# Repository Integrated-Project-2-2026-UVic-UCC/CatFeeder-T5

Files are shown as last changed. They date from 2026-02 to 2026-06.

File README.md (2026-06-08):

# 🐱 Automatic Cat Feeder

Modular automatic cat feeder based on an ESP32 microcontroller, a NEMA 17 stepper motor, closed-loop weight feedback, scheduled feeding, and local user interaction through a TFT touch display.

The goal of this project is to design and build a low-cost mechatronic prototype capable of dispensing controlled portions of dry cat food at scheduled times. The system combines mechanical design, 3D printing, electronics, embedded firmware, sensor calibration, and power management.

---

<p align="center">
  Automatic Cat Feeder Prototype
</p>

## 📌 Project Overview

Automatic cat feeders are useful embedded systems because they combine several engineering areas in a single functional product:

* Mechanical food storage and dispensing.
* Stepper motor actuation.
* Weight-based portion control.
* Real-time scheduling.
* Sensor integration.
* Local user interface.
* Power supply and backup operation.

This prototype uses an auger screw mechanism driven by a NEMA 17 stepper motor. The amount of food dispensed is measured using a load cell and an HX711 amplifier, allowing the system to stop the motor when the target portion has been reached.

---

## 🎥 Commercial Video

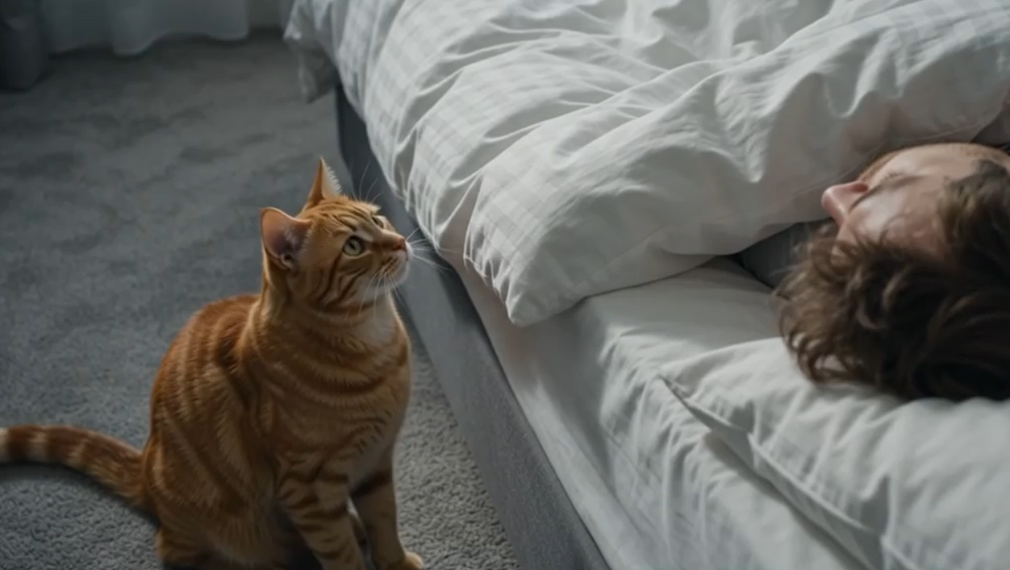
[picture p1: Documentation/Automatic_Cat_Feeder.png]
Watch the commercial video (https://universitatdevic.sharepoint.com/:v:/t/IntegratedProjectII-GR15GEMEC-09UV-Equip/IQAjYwX-qLkBQKHNnmvlTQq8AcUehd5CAwjfhSMxtLNW64w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)


Click the image above to watch the commercial video of the Automatic Cat Feeder prototype.

---

## 🎯 Main Features

* Scheduled automatic feeding.
* Manual food dispensing.
* Closed-loop portion control using a load cell.
* NEMA 17 stepper motor actuation.
* DRV8825 stepper motor driver.
* ESP32 WROOM-32 control unit.
* DS3231 real-time clock for offline timekeeping.
* DHT22 temperature and humidity monitoring.
* 3.5-inch TFT touch display for local interaction.
* 12 V UPS / battery system for backup power.
* Modular mechanical design with 3D-printed parts.
* Low-cost prototype architecture.

---

## 🧩 System Architecture

The prototype is divided into four main subsystems:

| Subsystem | Description |
| --- | --- |
| Mechanical system | Food hopper, main body, auger screw, motor mount, bowl support, and electronics enclosure |
| Electrical system | ESP32, DRV8825, NEMA 17 motor, HX711, load cell, RTC, DHT22, TFT display, and UPS |
| Firmware | Feeding logic, motor control, sensor reading, scheduling, calibration, and user interface |
| Validation | Portion accuracy tests, repeatability tests, scheduled feeding tests, and power consumption tests |

The food is stored in the upper hopper and moves by gravity toward the lower dispensing area. The auger screw moves the food toward the outlet, while the load cell measures the real amount of food dispensed into the bowl.

---

## 🛠️ Mechanical Design

The mechanical structure is designed to be manufactured mainly using FDM 3D printing. The prototype prioritizes low cost, modularity, ease of assembly, and adaptability to different dry food sizes.

### 3D-Printed Parts

| Part | Description | Recommended Material | Notes |
| --- | --- | --- | --- |
| Main body | Main structural frame of the feeder | PLA / PETG | Supports the hopper, motor, electronics, and bowl area |
| Food hopper | Stores dry cat food | PETG recommended | Smooth internal walls recommended |
| Auger screw / dispensing screw | Moves food from the hopper to the outlet | PETG recommended | Must be tested with the real kibble size |
| Bowl support | Holds the bowl and load cell system | PLA / PETG | Should avoid unwanted movement during weighing |
| Motor mount | Holds the NEMA 17 motor in position | PETG / ABS | Must keep the motor aligned with the dispensing screw  |
| Electronics cover | Protects the electronics and wiring | PLA / PETG | Ventilation openings recommended |

---

## 🧾 Mechanical and Hardware Parts

The mechanical structure of the feeder is based mainly on 3D-printed parts and standard assembly hardware. The final dimensions and quantities may vary depending on the selected enclosure, hopper size, and screw mechanism.

| Image | Part | Description | Quantity | Notes |
| --- | --- | --- | ---: | --- |
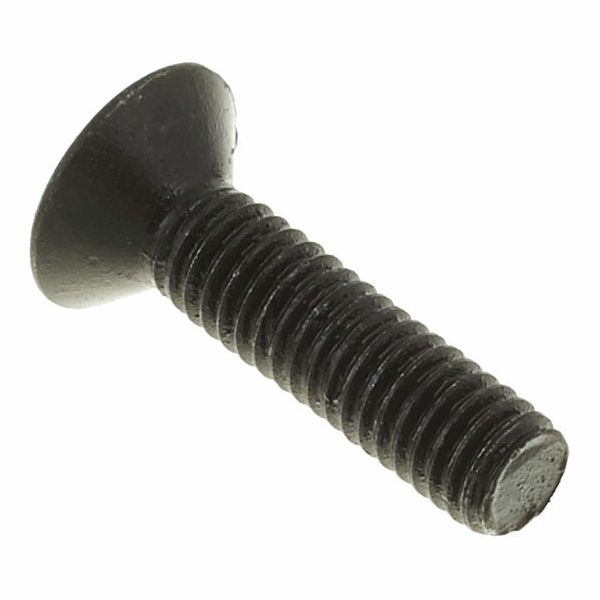
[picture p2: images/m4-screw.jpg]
|  | M4 screws | General assembly screws | 10–20 pcs | Final length depends on the 3D-printed parts  |
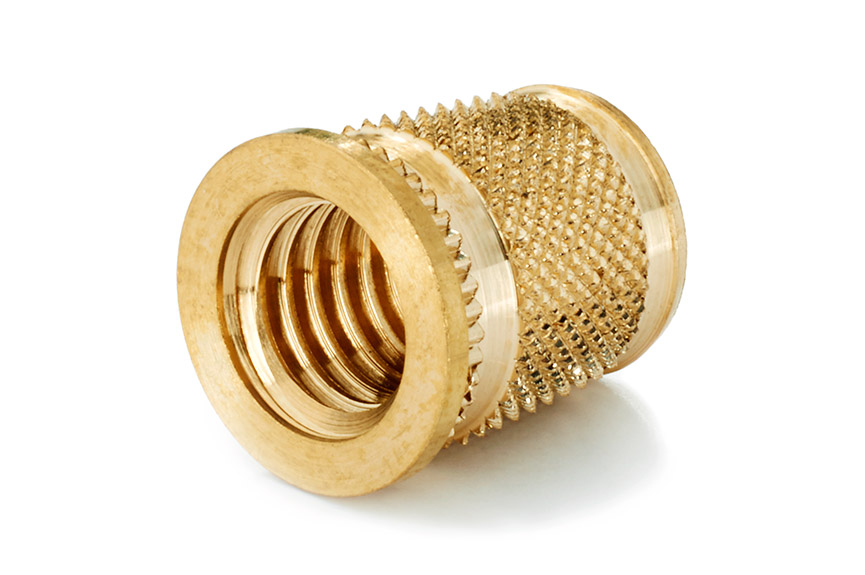
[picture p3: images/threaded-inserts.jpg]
|  | Threaded inserts | Metal inserts for stronger screw mounting | Optional | Recommended for repeated disassembly |
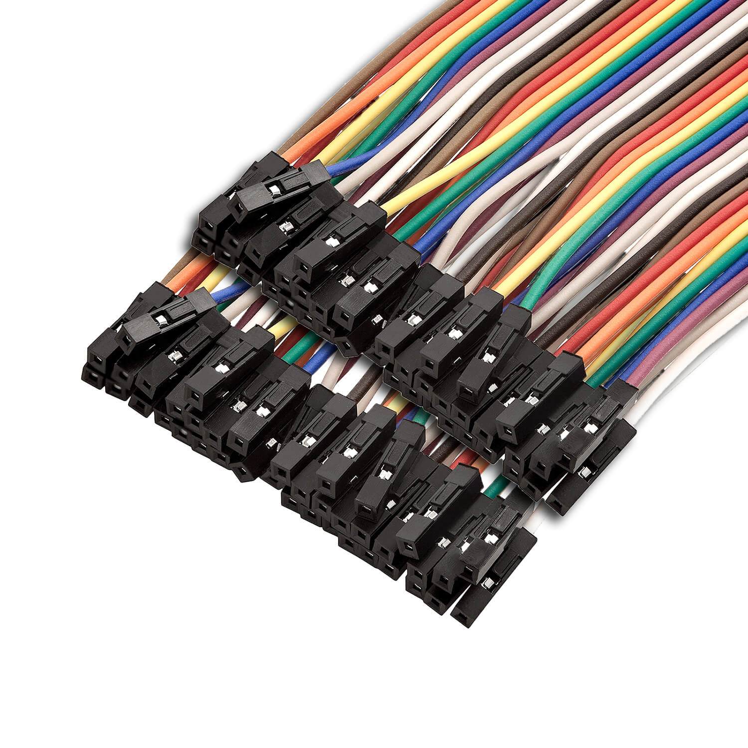
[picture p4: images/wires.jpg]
|  | Wires / jumper cables | Electrical connections | As required | Use suitable wire gauge for motor power lines |
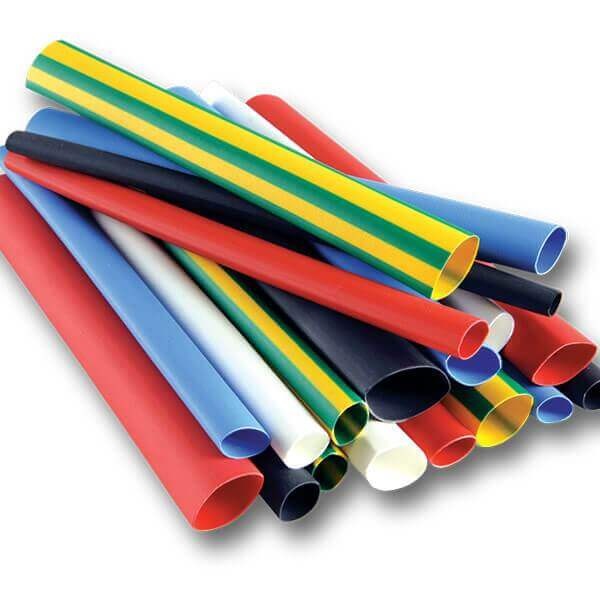
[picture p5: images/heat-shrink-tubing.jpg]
|  | Heat-shrink tubing | Wire insulation and protection | As required | Recommended for safer wiring |

---

## ⚡ Electronic Components

The electrical architecture is built around the ESP32 WROOM-32 microcontroller. The ESP32 controls the actuator, reads the sensors, manages the feeding schedule, and communicates with the local user interface.

| Image | Component | Quantity | Description | Purpose |
| --- | --- | ---: | --- | --- |
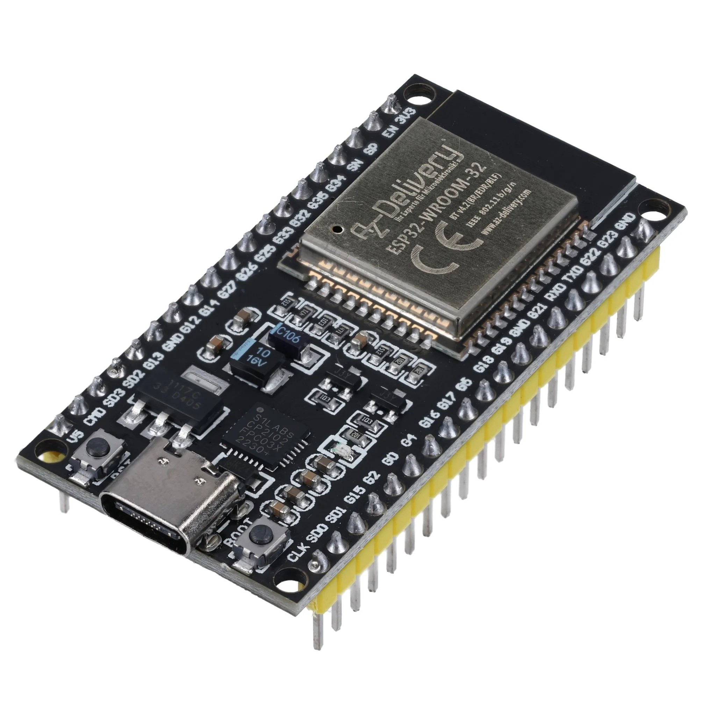
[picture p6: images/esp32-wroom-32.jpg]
|  | ESP32 WROOM-32 | 1 | Wi-Fi and Bluetooth capable microcontroller | Main control unit |
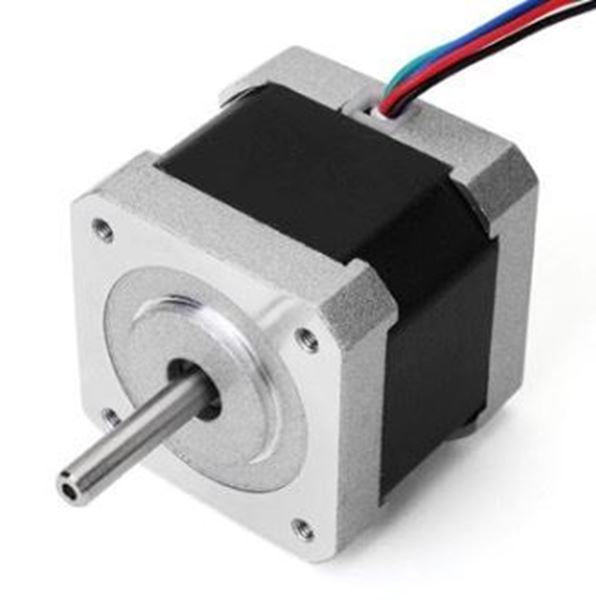
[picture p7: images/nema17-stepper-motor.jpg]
|  | NEMA 17 stepper motor | 1 | Bipolar stepper motor | Rotates the dispensing mechanism |
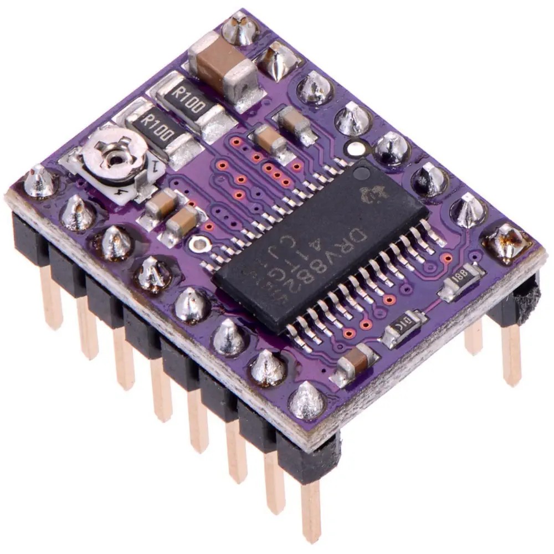
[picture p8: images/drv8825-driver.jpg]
|  | DRV8825 stepper motor driver | 1 | Stepper motor driver module | Drives the NEMA 17 motor from ESP32 control signals |
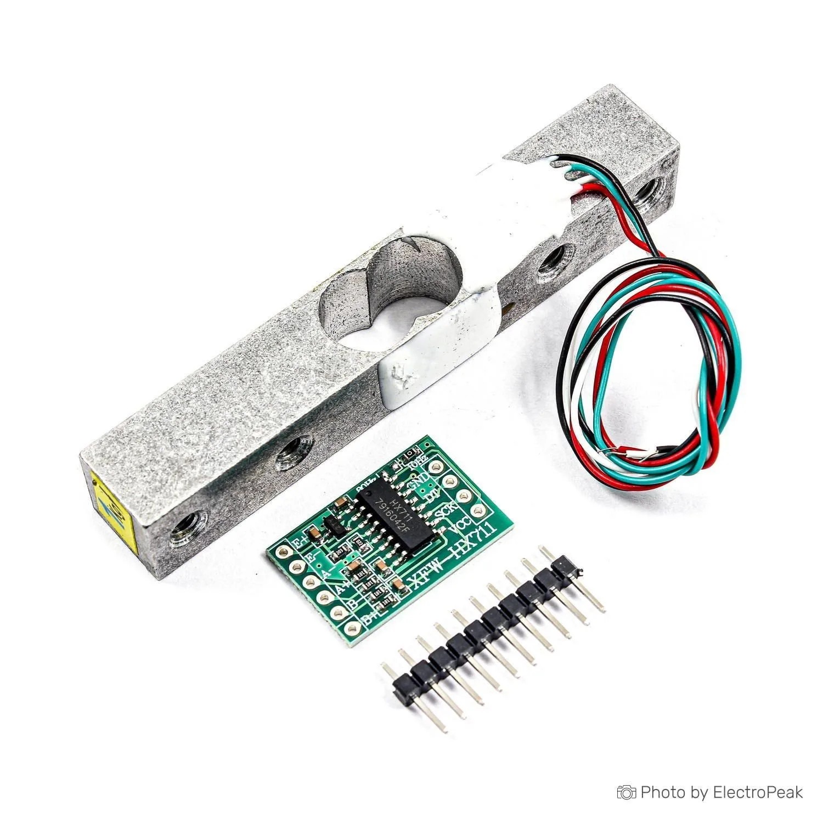
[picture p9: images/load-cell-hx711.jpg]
|  | Load cell 1 kg + HX711 | 1 | Weight sensor and 24-bit ADC amplifier | Measures the dispensed food portion |
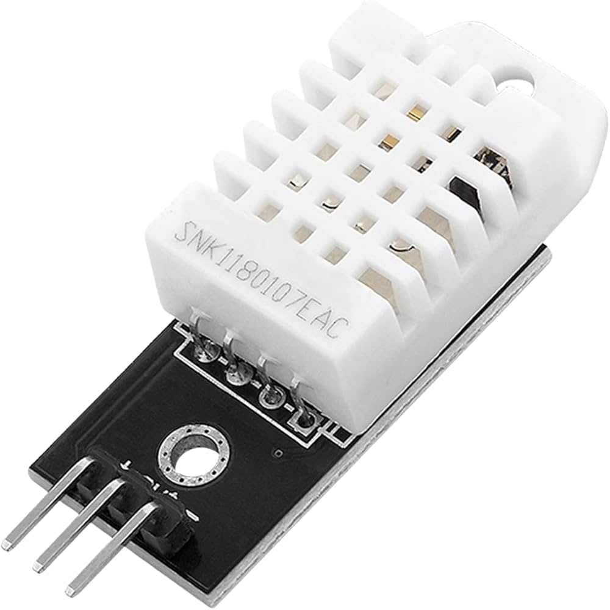
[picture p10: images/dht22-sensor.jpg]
|  | DHT22 | 1 | Temperature and humidity sensor | Monitors food storage conditions |
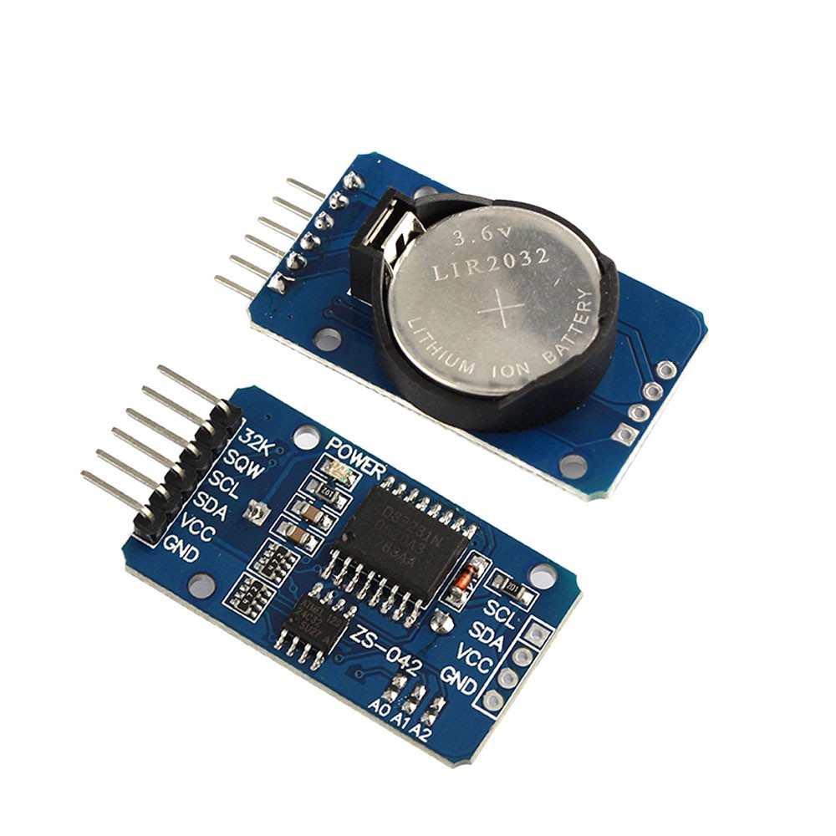
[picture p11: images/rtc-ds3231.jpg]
|  | RTC DS3231 | 1 | Real-time clock module | Keeps accurate feeding schedules without Wi-Fi |
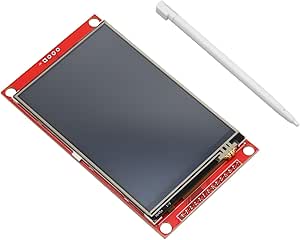
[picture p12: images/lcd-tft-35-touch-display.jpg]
|  | 3.5-inch TFT touch display | 1 | Local touchscreen interface | Displays information and allows local configuration |
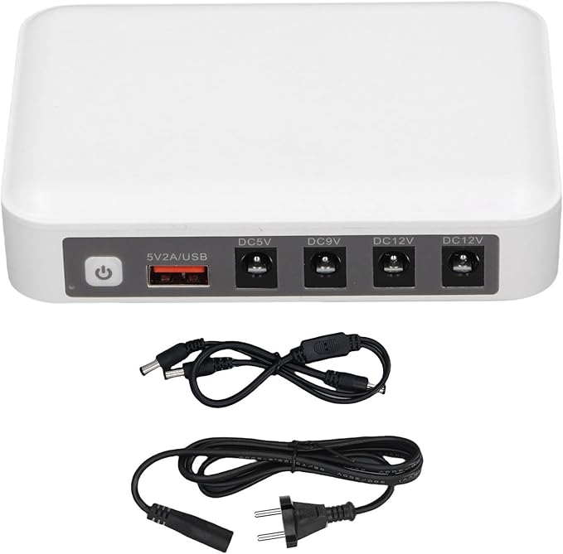
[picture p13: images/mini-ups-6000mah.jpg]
|  | 12 V Mini UPS / battery system | 1 | Backup power supply | Keeps the feeder powered during short outages |
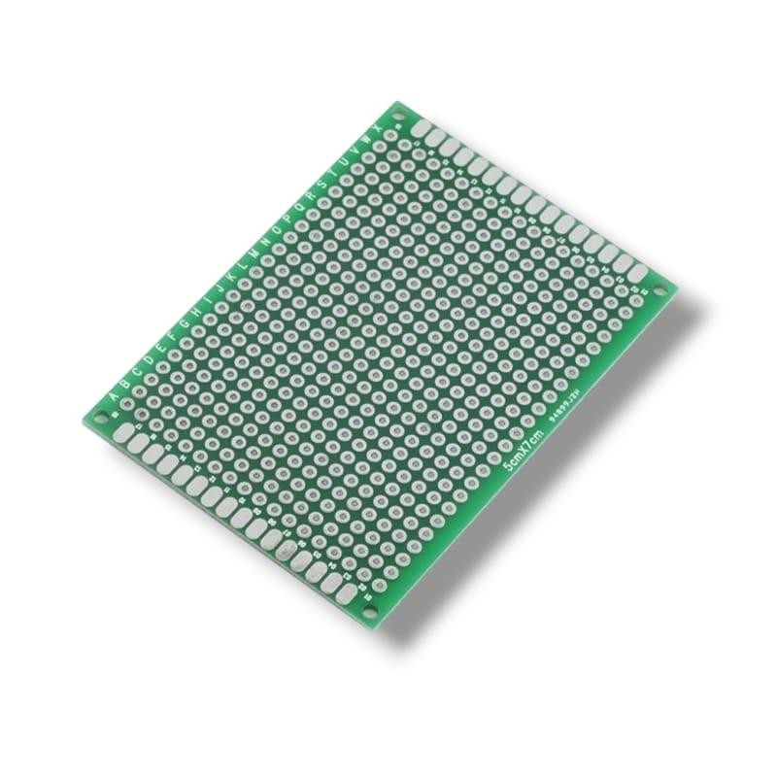
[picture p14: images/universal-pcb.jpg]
|  | Universal double-sided PCB | 1 | Prototyping PCB | Used for mounting and organizing the circuit |

---

## 🔌 Power Architecture

The system uses three voltage levels:

| Voltage Rail | Usage |
| --- | --- |
| 12 V | NEMA 17 stepper motor through the DRV8825 driver |
| 5 V | ESP32 development board and selected modules |
| 3.3 V | ESP32 logic level and compatible low-power modules |

All voltage rails must share a common ground reference. This is required to ensure that control signals and sensor communication lines are interpreted correctly.

> ⚠️ The DRV8825 current limit must be adjusted according to the rated current of the selected NEMA 17 motor. A bulk capacitor should also be placed close to the motor power input of the driver to reduce voltage spikes generated by the inductive load.

---

## 🧠 ESP32 GPIO Mapping

| Target Component | Peripheral Pin | ESP32 GPIO | Description |
| --- | --- | ---: | --- |
| DRV8825 | STEP | GPIO 26 | Step pulse output |
| DRV8825 | DIR | GPIO 27 | Direction control |
| DRV8825 | ENABLE | GPIO 14 | Driver enable / power saving  |
| HX711 | DOUT | GPIO 32 | Load cell data |
| HX711 | PD_SCK | GPIO 33 | Load cell clock |
| DS3231 RTC | SDA | GPIO 21 | I2C data |
| DS3231 RTC | SCL | GPIO 22 | I2C clock |
| DHT22 | DATA | GPIO 4 | Temperature and humidity data |
| TFT Display | SPI_CLK | GPIO 18 | SPI clock |
| TFT Display | SPI_MISO | GPIO 19 | SPI MISO |
| TFT Display | SPI_MOSI | GPIO 23 | SPI MOSI |
| TFT Display | TFT_CS | GPIO 15 | Display chip select |
| TFT Display | TFT_DC | GPIO 2 | Data / command selection |

> ⚠️ Some ESP32 pins are strapping pins and can affect boot behaviour. GPIO 0, GPIO 2, GPIO 5, GPIO 12, and GPIO 15 must be used carefully.

---

## 💻 Firmware

The firmware is developed in C/C++ using the Arduino framework for ESP32.

The software controls:

* Scheduled feeding.
* Manual dispensing.
* Motor movement.
* Load cell readings.
* RTC timekeeping.
* DHT22 environmental readings.
* TFT display interface.
* Basic safety checks.
* Power-saving behaviour.

---

## 🔁 Control Algorithm

The feeding cycle follows this sequence:

1. Read the current time from the DS3231 RTC.
2. Compare the current time with the programmed feeding schedule.
3. If a feeding event is required, enable the DRV8825 driver.
4. Start rotating the NEMA 17 motor.
5. Move food through the auger screw.
6. Read the load cell using the HX711 amplifier.
7. Compare the measured weight with the target portion.
8. Stop the motor when the desired portion is reached.
9. Disable the motor driver to reduce power consumption.
10. Store or display the feeding result.

---

## ⚖️ Calibration

Calibration is required before using the feeder.

### Load Cell Calibration

The load cell must be calibrated using known reference weights.

Recommended process:

1. Place the empty bowl on the load cell.
2. Tare the system.
3. Place a known weight on the bowl.
4. Read the raw HX711 value.
5. Calculate the scale factor.
6. Repeat the process with different weights.
7. Store the final calibration factor in the firmware configuration.

### Portion Calibration

Different dry foods have different shapes and densities. For this reason, the dispensing system must be tested with the real kibble.

Recommended process:

1. Set a target portion, for example 20 g.
2. Run the dispensing cycle.
3. Measure the real dispensed mass.
4. Repeat several times.
5. Calculate the average error.
6. Adjust motor speed, acceleration, or stopping threshold if required.

---

## 🧪 Validation Tests

| Test | Objective | Expected Result |
| --- | --- | --- |
| Dispensing mechanism test | Verify food movement through the auger screw | Food is dispensed without blockage |
| Portion accuracy test | Compare target mass with real mass | Low dispensing error |
| Repeatability test | Repeat the same portion several times | Similar mass between cycles |
| Scheduled feeding test | Verify RTC-based activation | Feeder activates at programmed times |
| Power consumption test | Measure 12 V and 5 V consumption | Consumption within estimated range |

---

## 📊 Technical Targets

| Parameter | Target / Estimated Value |
| --- | ---: |
| Food capacity | Approximately 3 kg |
| Estimated autonomy |  Approximately 45.6 days |
| Daily food quantity | Approximately 65.8 g/day |
| Required motor torque | 0.199 N·m |
| Selected motor torque | 0.4 N·m |
| Safety factor | 2.01 |
| Estimated daily energy consumption | 0.73–2 Wh/day |

---

## 🧮 Prototype Material Cost

| Item | Component | Quantity | Unit Price [€] | Cost [€] | Provider  |
| ---: | --- | ---: | ---: | ---: | --- |
| 1 | NEMA 17 stepper motor | 1 | 14.00 | 14.00 | Amazon |
| 2 | ESP32 WROOM-32 | 1 | 13.00 | 13.00 | Amazon |
| 3 | Load Cell 1 kg + HX711 | 1 | 20.00 | 20.00 | Amazon |
| 4 | DHT22 temperature and humidity sensor | 1 | 9.99 | 9.99 | Robotshop |
| 5 | PLA 1 kg | 1 | 13.00 | 13.00 | Amazon |
| 6 | Universal double-sided PCB, 9 x 15 cm, 10 units | 1 | 10.17 | 10.17 | Amazon |
| 7 | DRV8825 stepper motor driver | 1 | 19.24 | 19.24 | Robotshop |
| 8 | RTC DS3231 | 1 | 4.50 | 4.50 | Amazon |
| 9 | SAI Mini UPS 6000 mAh | 1 | 39.90 | 39.90 | Amazon |
| 10 | 3.5-inch LCD TFT touch display | 1 | 16.14 | 16.14 | Amazon |
| | **Total material cost** | | | **159.94** | |

---

## 🧯 Safety Notes

* Do not power the NEMA 17 motor directly from the ESP32.
* Always use a dedicated stepper motor driver.
* Adjust the DRV8825 current limit before connecting the motor.
* Use a common ground between the ESP32, driver, sensors, and power supply.
* Avoid loose wires near the moving dispensing mechanism.
* Protect the electronics from food dust and humidity.
* Test the system without food before performing real dispensing tests.
* Do not leave the feeder unattended until the prototype has been validated.
* Disconnect the power supply before modifying wiring.
* Check motor and driver temperature during long tests.

---

## 🚀 Future Improvements

* Mobile application integration.
* Remote configuration through a cloud backend.
* Food level detection.
* Improved enclosure design.
* Better humidity protection.
* Long-term reliability testing.
* Advanced calibration procedure.
* Notification system for low food level or failed dispensing.
* AI-assisted feeding analysis based on historical data.
* Improved user interface for feeding schedules and calibration.
* Additional safety detection for mechanical jams.

---

## 👥 Authors

* Ferran Vila Ordeig
* Biel Tomàs Rifà
* Pol Roch Jose
* Georgina Garcia Vilaseca

Degree in Mechatronics Engineering
Subject: Integrated Projects II
University of Vic - Central University of Catalonia

---

## 📄 License

This project is intended for academic and educational purposes.

Add a license file if the project is going to be published publicly.

Recommended licenses:

* MIT License for open-source software.
* CERN Open Hardware Licence for hardware designs.
* Creative Commons license for documentation and 3D models.

---

## 📚 Documentation

The complete technical document includes:

* State of the art and benchmarking.
* Objectives.
* Mechanical design.
* Electrical design.
* Design calculations.
* Control strategy.
* Functional testing plan.
* Cost estimation.
* Conclusions.
* Electrical schematic appendix.

The final report should be stored in the `docs/` folder when available.

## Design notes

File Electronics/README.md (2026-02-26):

# ⚡ Electronics System  
**Automatic Cat Feeder – Integrated Project II (GR15 [GEMEC-09UV])**  
Universitat de Vic – Universitat Central de Catalunya  
Academic Year 2025–2026  

---

## 📌 Overview

This folder contains the complete design and documentation of the **electronic subsystem** of the automatic cat feeder.

The electronics system is responsible for:

- Precise motor control  
- Accurate weight measurement  
- Reliable time-based operation  
- Safe power distribution  
- Hardware-level protection mechanisms  

The design prioritizes **robustness, electrical safety, noise immunity, and modular expandability**, ensuring reliable long-term operation under real-world conditions.

---

## 🎯 Electronics Objectives

- Provide stable and regulated power to all subsystems  
- Control the dispensing motor safely and efficiently  
- Measure dispensed food weight using a load cell system  
- Interface reliably with the microcontroller (ESP32 / Arduino-based platform)  
- Prevent electrical faults (overcurrent, reverse polarity, voltage spikes)  
- Minimize electromagnetic interference (EMI)  
- Ensure maintainability and future scalability  

---

## 🧩 System Architecture

The electronics subsystem is composed of the following modules:

### 1️⃣ Control Unit
- Microcontroller (ESP32 / Arduino platform)  
- GPIO control for motor driver  
- HX711 communication (load cell ADC)  
- Scheduling interface with firmware  

### 2️⃣ Motor Control Stage
- DC motor driver 
- Flyback protection  
- Current limitation strategy  
- Thermal considerations  

### 3️⃣ Weight Measurement System
- Load cell (strain gauge bridge)  
- HX711 24-bit ADC  
- Hardware noise filtering  
- Stable reference and grounding strategy  

### 4️⃣ Power Management
- Input supply stage  
- Voltage regulation (buck / linear regulators)  
- Reverse polarity protection  
- Decoupling and filtering  
- Star-ground topology  

---

## 📂 Folder Structure
electronics/

- schematics/          → Circuit schematics (PDF / CAD files)
- pcb/                 → PCB layout files (if applicable)
- datasheets/          → Relevant component datasheets
- calculations/        → Design calculations (power, current, filtering)
- testing/             → Validation and measurement reports
- README.md            → This document

---

## ⚙️ Key Components

| Component | Function |
|---|---|
| ESP32 / Arduino  | Main control unit |
| HX711 | 24-bit ADC for load cell |
| Load Cell | Food weight measurement |
| Motor Driver | DC motor control |
| Voltage Regulator| Stable power supply |

---

## 📚 References

- ESP32 Technical Reference Manual  
- HX711 Datasheet  
- Load Cell Application Notes  
- TI / ST Microelectronics Power Design Guidelines  
- IPC-2221 PCB Design Standard  

(Complete references available in Milestone documentation)

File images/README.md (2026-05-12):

# Images

This folder contains the images used in the main `README.md` file of the **Automatic Cat Feeder** project.

The images are mainly used to document the electronic components, mechanical parts, wiring, assembly process, and final prototype.

---

## Folder purpose

The purpose of this folder is to keep all project images organized in one place, instead of linking external images directly inside the README.

This makes the documentation easier to maintain and more reliable when the project is uploaded to GitHub.

---

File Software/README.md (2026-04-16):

# CatFeeder - Software Components

This directory contains the entire software stack for the smart CatFeeder project, consisting of a production-grade web application, an IoT firmware simulation, and supporting design resources.

## Architecture Overview

The software is divided into the following main functional components:

1.  **Web Application (`webapp/`)**: A React-based interface allowing users to monitor their cat's data, manage feeding schedules, and interact with the physical device.
2.  **Firmware Mock (`firmware/`)**: An Arduino C++ firmware for the ESP32 that completely mocks the physical sensors and actuators (to be replaced with actual physical components).
3.  **Agent Resources (`agent/`)**: Skills and guidelines focusing on strong frontend design aesthetic and prompt specifications.
4.  **Specifications & Design Assets**:
    *   `SRS_CatFeeder_WebApp.docx.md`: The Software Requirements Specification outlining system capabilities.
    *   `diseño_ui.png`: High-fidelity UI design reference.

---

## 1. Web Application (`webapp/`)

A responsive, bespoke frontend application designed with a strong emphasis on intentional aesthetics and smooth performance. It serves as the primary control panel for the project.

### Tech Stack & Libraries
*   **React 19 & Vite**: The core foundation, providing blazing-fast initialization and HMR.
*   **React Router v7**: For robust client-side routing across sections (*Dashboard, Cats, Schedules, History, Device, Settings, Chat*).
*   **Supabase Client**: Provides BaaS capabilities for PostgreSQL database interactions, real-time subscriptions, and authentication (`@supabase/supabase-js`).
*   **Zustand**: A small, fast, and scalable bearbones state-management solution for handling authentication sessions and global UI state.
*   **Recharts**: Used for rendering visual data analytics, such as the history of cat feeding patterns and weight variations.
*   **Vanilla CSS**: Custom styling following strict frontend design mandates. Prevents over-reliance on utility frameworks, achieving a distinct and premium interface.

### Application Workflow
1.  **Auth & Session**: Handled globally in `App.jsx` using `useAuthStore` (Zustand). Only authenticated users are routed past the `<PrivateRoute>` wrapper into the layout.
2.  **Database Integration**: Pages execute queries using the Supabase client to fetch table information (`cats`, `schedules`, `commands`, `devices`, `feed_events`).
3.  **Hardware Control**: To dispense food or tare the scale, the webapp pushes a new row into the `commands` table. The ESP32 device actively listens to this table.
4.  **Real-time Monitoring**: The dashboard visualizes telemetry (temperature, humidity, scale weight) inserted into Supabase by the physical device.

### Running Locally
You will need Node.js installed. In your terminal:
```bash
cd webapp
npm install 
npm run dev
```
*(Ensure `.env` contains your `VITE_SUPABASE_URL` and `VITE_SUPABASE_ANON_KEY` variables to successfully interact with the database).*

---

## 2. Firmware Simulation (`firmware/`)

Located at `firmware/CatFeeder_Mock/CatFeeder_Mock.ino`, this Arduino C++ instance ensures full end-to-end functionality of the platform without needing the final hardware assembly.

### Core Features
*   **Target Board**: Designed for ESP32 (WROOM-32).
*   **Direct Cloud Integration**: Connects straight to the Supabase REST API via `HTTPClient` and `WiFiClientSecure` using an API JWT authorization header.
*   **Bi-directional Communication**:
    *   **Polling (GET)**: Fetches `device_config` (every 60s) and checks the `commands` table for pending actions (every 5s).
    *   **Pushing (POST/PATCH)**: Sends `realtime_weight` during active operations (`500ms`) and updates device `heartbeat` statuses.
*   **Virtual Sensors & Actuators**: Calculates pseudo-random Gaussian noise behavior across variables:
    *   **Scale**: Mimics the HX711 Load Cell behaviors.
    *   **Environment**: Simulates a DHT22 module to relay Temperature & Humidity.
    *   **Dispenser Motor**: Simulates DRV8825 logic with timeout safety guards, "dispensing" at a fake `8.0g/s` feed rate.

### Usage Setup
1.  Open `CatFeeder_Mock.ino` with the Arduino IDE. 
2.  Install the **ArduinoJson** (`v7.x`) library from the Library Manager.
3.  Update the network credentials (`WIFI_SSID`, `WIFI_PASS`) and endpoint configs (`SUPABASE_URL`, `SUPABASE_KEY`, `DEVICE_ID`).
4.  Upload to your ESP32 board and open the Serial Monitor at `115200` baud.

---

## 3. Architectural Note

This software adopts an asynchronous, database-as-the-broker architecture. The web application and the ESP32 never communicate with each other directly; they only write to or listen to the Supabase database. This guarantees a decoupled, resilient system. Row Level Security (RLS) rules in Supabase must be set up properly to make sure IoT requests only interact with permitted device rows.

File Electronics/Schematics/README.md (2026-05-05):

# Schematics

This folder contains the electrical schematics of the Automatic Cat Feeder project.

The schematics define how the electronic components are connected, including the microcontroller, sensors, actuators, power supply, protection elements, and communication signals.

## Purpose

The purpose of this folder is to:

- Document the electrical design of the project.
- Show how each electronic component is connected.
- Support wiring, debugging, and testing.
- Keep editable schematic files and exported versions organized.
- Track changes between schematic revisions.
- Help detect electrical design errors before assembly.

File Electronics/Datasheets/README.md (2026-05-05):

# Datasheets

This folder contains the datasheets of the main electronic components used in the Automatic Cat Feeder.

Only components that are electrically relevant, safety-critical, or necessary for integration are included.
Generic components such as wires, screws, standard resistors, and simple connectors are documented in the BOM instead.

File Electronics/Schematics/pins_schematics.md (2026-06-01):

| GPIO | TFT SCREEN | TOUCH XPT2046 | DRV8825 | LOAD CELL HX711 | DHT22 | DS3231 / AT24C32 |
| --- | --- | --- | --- | --- | --- | --- |
| 0 |  |  |  |  |  |  |
| 1 |  |  |  |  |  |  |
| 2 |  |  |  |  |  |  |
| 3 |  |  |  |  |  |  |
| 4 | RESET |  |  |  |  |  |
| 5 | CS |  |  |  |  |  |
| 6 |  |  |  |  |  |  |
| 7 |  |  |  |  |  |  |
| 8 |  |  |  |  |  |  |
| 9 |  |  |  |  |  |  |
| 10 |  |  |  |  |  |  |
| 11 |  |  |  |  |  |  |
| 12 |  |  |  |  |  |  |
| 13 |  |  |  |  |  |  |
| 14 |  |  |  |  | DATA |  |
| 15 |  |  |  |  |  |  |
| 16 |  |  |  | DT |  |  |
| 17 |  |  |  | SCK |  |  |
| 18 | SCK | T_CLK |  |  |  |  |
| 19 |  | T_DO |  |  |  |  |
| 20 |  |  |  |  |  |  |
| 21 |  | T_CS |  |  |  |  |
| 22 | DC |  |  |  |  |  |
| 23 | SDI/MOSI | T_DIN |  |  |  |  |
| 24 |  |  |  |  |  |  |
| 25 |  |  | EN |  |  |  |
| 26 |  |  | STEP |  |  |  |
| 27 |  |  | DIR |  |  |  |
| 28 |  |  |  |  |  |  |
| 29 |  |  |  |  |  |  |
| 30 |  |  |  |  |  |  |
| 31 |  |  |  |  |  |  |
| 32 |  |  |  |  |  | SDA |
| 33 |  |  |  |  |  | SCL |
| 34 |  |  |  |  |  |  |
| 35 |  |  |  |  |  |  |
| GND | GND | GND | GND | GND | GND | GND |
| VCC | VCC | VCC | VCC | VCC | VCC | 3V3 |

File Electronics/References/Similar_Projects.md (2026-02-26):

## I made an automatic pet feeder - Part 1 DIY Arduino project PEDRO
https://www.youtube.com/watch?v=Uv0lsih8JRA&t=21s

## A DIY Pet Feeder based on ESP8266
https://www.youtube.com/watch?v=lJUztOnBgxA

## Automatic cat feeder with stepper motor and ATMega AVR

https://www.youtube.com/watch?v=xrDOFbLw8pU

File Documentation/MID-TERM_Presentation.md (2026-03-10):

## MID-TERM PRESENTATION

---

### SLIDE 1 - Title Slide

**Automatic Cat Feeder**  
**Integrated Project II - Mid-Term Presentation**

- Team: T5
- Course: Integrated Project II
- Institution: Universitat de Vic – Universitat Central de Catalunya
- Academic Year: 2025–2026

#### Speaker notes:
This presentation summarizes the current state of the Automatic Cat Feeder project at mid-term.  
We will present the project objectives, team organization, planning methodology, the current prototype status, website and GitHub progress, and the next steps toward the final delivery.

---

### SLIDE 2 - Project Objectives

#### Text on slide

**Main Objective**

Design and implement an automatic cat feeder capable of reliable, safe, and autonomous dispensing of controlled food portions at scheduled times.

**Specific Objectives**

- Develop a scheduling system for automatic feeding
- Ensure controlled and repeatable food portions
- Improve reliability and safety during operation
- Reduce the need for constant human intervention

#### Speaker notes:
The main goal of the project is to create an automatic feeder that can dispense food in a reliable, safe, and autonomous way.  
The system must deliver food at programmed times and in controlled portions.  
This helps guarantee regular feeding while avoiding overfeeding, underfeeding, and unnecessary food waste.

---

### SLIDE 3 - Team Organization and Roles

#### Text on slide

**Project Manager**  
- Biel Tomàs Rifà  
- Oversees project coordination

**Mechanical Leader**  
- Pol Roch Jose  
- Leads mechanical design efforts

**Electronics Leader**  
- Georgina Garcia Vilaseca  
- Manages hardware integration

**Software Leader**  
- Ferran Vila Ordeig  
- Develops control algorithms

#### Speaker notes:
The project is organized with clearly defined responsibilities.  
The project manager coordinates the overall development, planning, and communication.  
The mechanical leader is responsible for the structural and feeder mechanism design.  
The electronics leader handles hardware integration, and the software leader develops the control logic and programming of the system.

---

### SLIDE 4 - Project Organization and Management

#### Text on slide

**Working Method**

- Sprint-based planning
- Progressive prototype development
- Shared task distribution across disciplines
- Periodic progress tracking

**Main Milestones**

- T1: Budgeting, schematics, design refinement
- T2: Component procurement and fabrication start
- T3: Electronics wiring, programming, mechanical assembly
- T4: Continuation of wiring, coding, and assembly
- T5: Finalizing assembly and starting functional tests
- T6: Code refinement and testing
- T7: Intensive functional testing
- T8: Final validation and presentation

#### Speaker notes:
The team follows a sprint-based work structure.  
Each sprint focuses on a specific set of goals, from design and procurement to assembly, testing, and final validation.  
This helps distribute the workload and monitor progress continuously.  
At the current stage, the project is transitioning from design and procurement into implementation and early testing.

---

### SLIDE 5 - Prototype Overview

#### Text on slide

**Prototype Purpose**

Develop an automatic feeder capable of dispensing food portions autonomously and safely.

**Main Characteristics**

- Automated food dispensing
- Scheduled operation
- Embedded control system
- Focus on accuracy, reliability, and modularity

**Innovation Aspects**

- Combination of mechanical dispensing and embedded control
- Open documentation approach
- Reproducible design with future scalability

#### Speaker notes:
The prototype combines a mechanical food delivery system with an embedded controller that manages timing and operation.  
The project emphasizes controlled dispensing, safe motor operation, and future modularity.  
A relevant aspect of the project is that it is being documented openly, which supports reproducibility and future improvements.

---

### SLIDE 6 - Prototype Current Status

#### Text on slide

**Completed / In Progress**

- General project concept defined
- Mechanical design direction established
- Electronics integration planned
- Programming logic under development
- Initial assembly and functional preparation ongoing

**Current Job Stoppers**

- Full hardware-software integration
- Functional validation of the dispensing mechanism
- End-to-end testing under real operating conditions

#### Speaker notes:
At mid-term, the project already has a defined technical direction.  
The overall concept, mechanical approach, and electronics strategy are established.  
Programming and integration are currently in development.  
The main remaining challenge is validating the complete system under real conditions and confirming that the dispensing mechanism performs consistently.

---

### SLIDE 7 - Mechanical, Electronics and Programming Status

#### Text on slide

**Mechanical Domain**

- Feeder mechanism design in progress
- Assembly planning underway
- Focus on reliable and repeatable dispensing

**Electronics Domain**

- Hardware integration defined
- Wiring and control electronics being implemented
- Safe motor operation considered a key requirement

**Programming Domain**

- Control logic under development
- Scheduling behavior being implemented
- Code refinement planned in later sprints

#### Speaker notes:
From the mechanical perspective, the project is focused on achieving a robust dispensing mechanism.  
From the electronics side, the integration of the controller and the actuator system is being prepared and implemented.  
In software, the priority is building the scheduling and control logic that will coordinate feeder operation safely and reliably.  
The next major milestone is to connect these three domains into a functional prototype.

---

### SLIDE 8 - Website Update

#### Text on slide

**Project Website Status**

- Website planned on GitHub Pages
- Open-source documentation approach
- Reproducible project steps
- Demonstration material will be included

**Purpose of the Website**

- Central hub for project documentation
- Public explanation of the system
- Support for replication and collaboration

#### Speaker notes:
The project website is intended to serve as the public-facing documentation hub.  
It will be hosted on GitHub Pages and will include project explanations, reproducible build steps, and demonstration content.  
This is important because the final project is expected to be documented clearly enough for other people to understand and replicate it.

---

### SLIDE 9 - GitHub Update

#### Text on slide

**Current GitHub Use**

- Project planning and milestones tracked
- Technical progress documented
- Code files to be uploaded and maintained
- Repository supports collaboration and version control

**Repository Should Include**

- Planning and milestones
- Weekly or periodic reports
- Code and technical files
- Calculations, schemes, and design documentation

#### Speaker notes:
GitHub is being used as the central repository for project management and technical development.  
It should contain the planning, milestone progress, reports, code, and technical documentation.  
For the final stages, it is important that all relevant design files, programming files, and implementation evidence are uploaded and organized correctly.

---

### SLIDE 10 - References and Documentation Inspiration

#### Text on slide

**Main References**

- DIY Automatic PetFeeder IoT (Instructables)
- MicroPython Auto Pet Feeder / ESP32 tutorial resources
- Market benchmarking from El País and Xataka
- ANFAAC sectoral data on pet ownership and market trends
- Additional YouTube project inspiration for feeder design

#### Speaker notes:
The project references include both technical and contextual sources.  
Instructables and ESP32/MicroPython resources provide implementation guidance for feeder logic and embedded integration.  
Market references help identify useful features and user expectations.  
Sectoral data also provides context on the relevance of automated pet care devices.

---

### SLIDE 11 - Mid-Term Conclusion

#### Text on slide

**Mid-Term Summary**

- Objectives are clearly defined
- Team roles and planning structure are established
- Prototype development is underway
- Website and GitHub documentation are in progress

**Next Milestone**

- Functional integrated prototype with initial testing

#### Speaker notes:
In conclusion, the project is progressing according to the expected mid-term path.  
The objectives, team structure, and planning are already defined, and the prototype is under active development.  
The next major goal is to complete the first integrated functional version and begin structured validation tests.

---

### SLIDE 12 - Questions

#### Text on slide

**Thank you for your attention**  
**Questions?**

#### Speaker notes:
Thank you for your attention.  
We are now ready to answer any questions about the project, its current status, and the next development stages.

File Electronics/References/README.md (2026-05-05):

# References

This folder contains external references used during the development of the electronics part of the Automatic Cat Feeder project.

The purpose of this folder is to keep track of useful technical sources, official documentation, tutorials, articles, standards, and design references that helped support design decisions.

## Purpose

The references stored here are used to:

- Justify technical decisions.
- Support component selection.
- Document external sources used during development.
- Keep useful links organized.
- Avoid losing important technical information.
- Distinguish project documentation from external information.

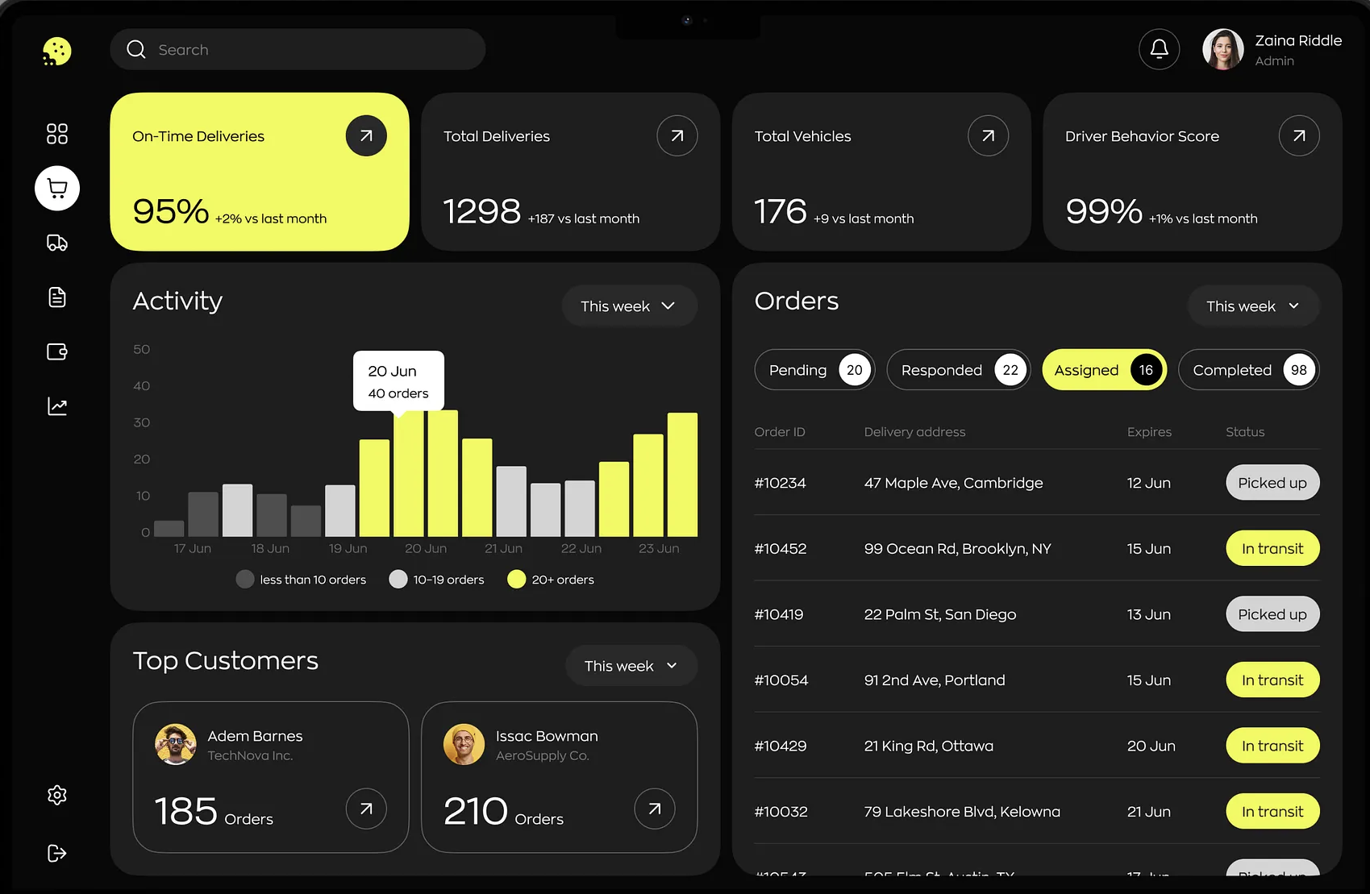
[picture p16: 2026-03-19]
Software/diseño_ui.png

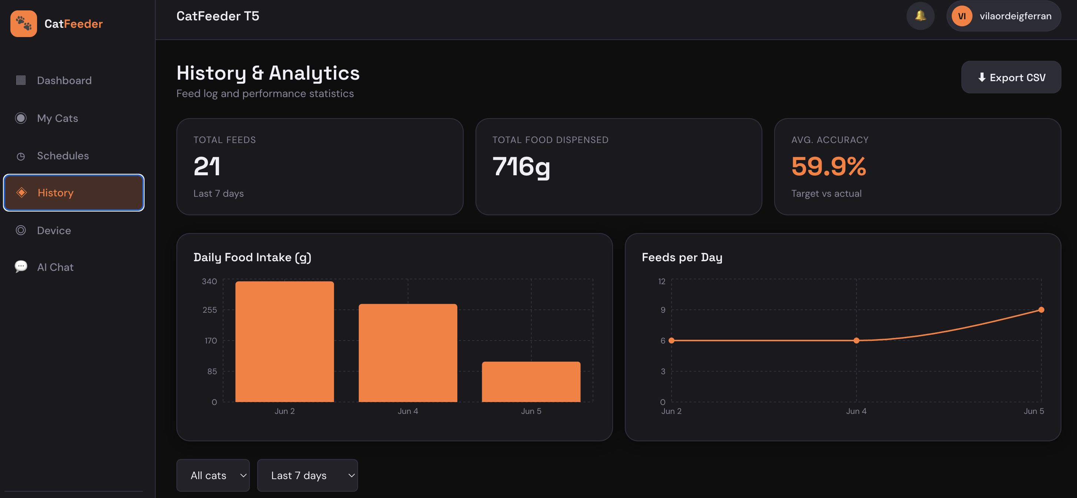
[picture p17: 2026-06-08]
images/Captura de pantalla 2026-06-07 a las 21.49.31.png

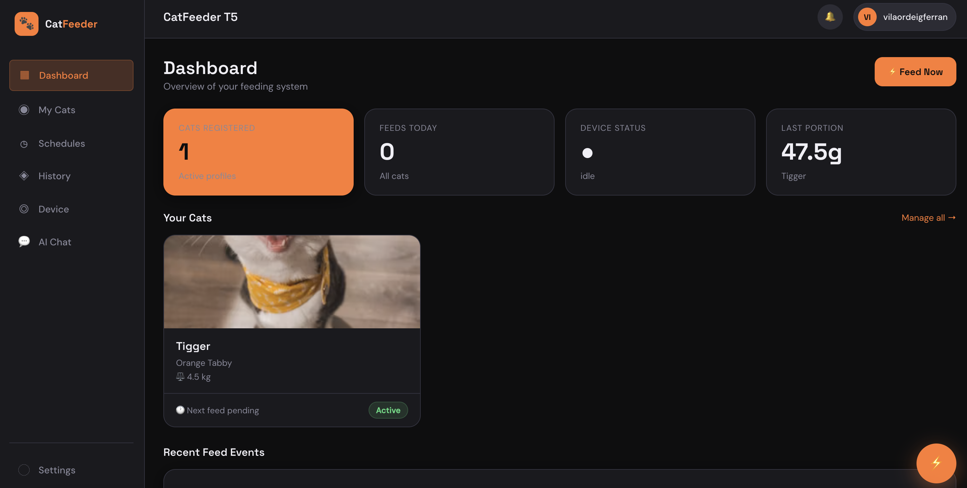
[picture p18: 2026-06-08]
images/Captura de pantalla 2026-06-07 a las 21.48.29.png

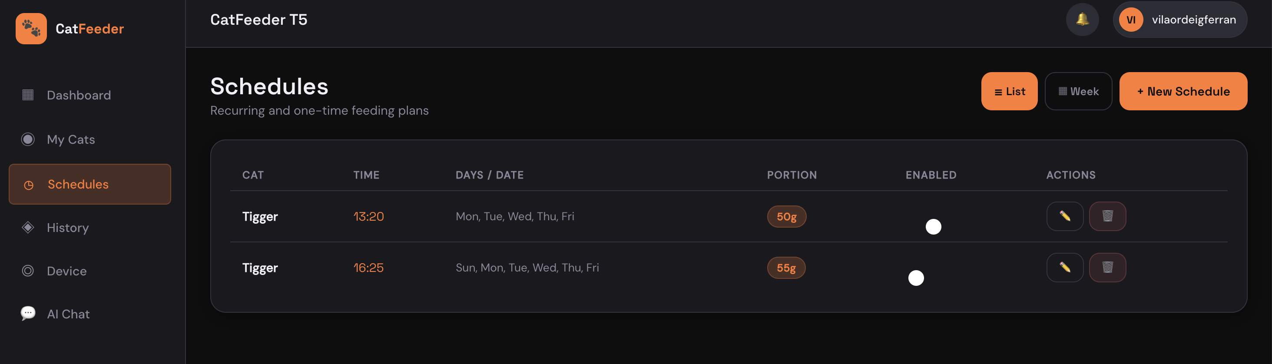
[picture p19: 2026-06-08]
images/Captura de pantalla 2026-06-07 a las 21.49.22.png

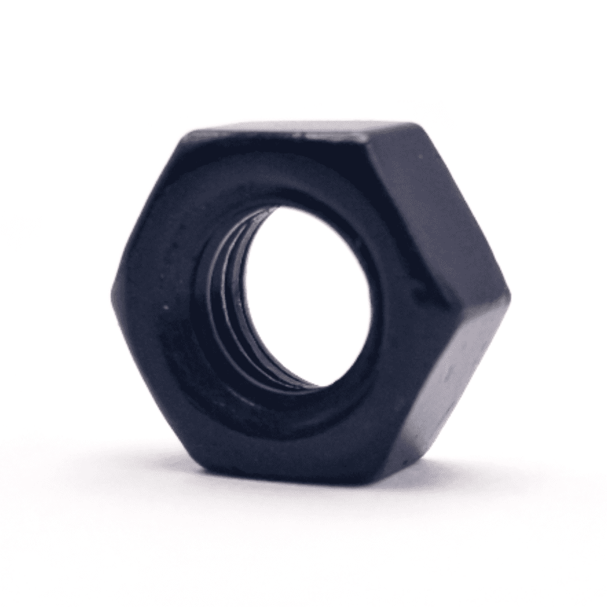
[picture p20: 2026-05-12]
images/m3-nuts.jpg

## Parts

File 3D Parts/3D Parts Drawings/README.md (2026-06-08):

# 🧩 3D-Printed Part Drawings

This folder contains the 3D-printed part drawings and mechanical design files for the **Automatic Cat Feeder** prototype.

The parts included here are used to build the mechanical structure of the feeder, including the food hopper, auger screw mechanism, motor mount, bowl support, and electronics enclosure.

---

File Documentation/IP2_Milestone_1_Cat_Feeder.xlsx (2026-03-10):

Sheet: Project Specifications
TECHNICAL SPECIFICATIONS
Customer Company | Universitat de Vic - Universitat Central de Catalunya
Engineering Company | Cat feeder
Revision 1 | Date: 24/02/2026
List the main characteristics of the desired device
Item number | Description
1 | Dispense food at configurable times (≥ 6 schedules/day).
2 | Adjustable portion size (±5% accuracy).
3 | Mobile app or web dashboard (WiFi).
4 | Operate during power outage (≥ 24h standby).
5 | Anti-Jam Detection
6 | Manual interaction (Physical button + Screen with menu)
7 | Measure dry pet food moisture content
8 | Cat identification with RFID (step 2)
Mechanical part
Dimensions (volume) | 250 mm x 400 mm x 400 mm (height)
Weight | 3,5 kg (dry food included)
Materials for the mechanical part / structure | 3D printed parts
Motors | 1
Manufacturing equipment | 3D Printer
Assembly between parts | Bolts and nuts, welding for electrical and electronics parts
Electronic & programming part
Microcontroller | 1 ESP32
Drivers | DRV8825
Sensors | Load cell 1 kg, Humidity sensor,
Communication | Via Wifi
Programming | Arduino IDE, Google Antigravity
Power | 12V 1600mAh Rechargeable NiMh Battery
Autonomy | 24 h
Protoboard | No

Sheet: Conceptual_Design
CONCEPTUAL DESIGN
Include an image (or more than one) with the current status of the conceptual design. Can be a sketches done with pencil

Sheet: Shopping list
PRELIMINAR ORDER LIST
Team: | Cat feeder |  | Total cost [€] | 167.14
 |  |  | Budget limit [€] | 300
Item number | Description of the material | Quantity | Price [€] | Cost [€] | Provider | Link / website
1 | NEMA 17 stepper motor | 1 | €14.00 | 14 | Amazon | https://www.amazon.es/Motor-pasos-imetx-Ender-extrusi%C3%B3n/dp/B0C36SWTCT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
2 | ESP32 WROOM-32 | 1 | €13.00 | 13 | Amazon | https://www.amazon.es/AZDelivery-NodeMCU-ESP-WROOM-32-Tablero-Desarrollo/dp/B071P98VTG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
3 | Load Cell 1kg + HX711 | 1 | €20.00 | 20 | Amazon | https://www.amazon.es/Wishiot-digitales-miniatura-electr%C3%B3nicos-port%C3%A1tiles/dp/B0CRDBJ8L7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
4 | DHT22 (Temperature & Humidity sensor) | 1 | €9.99 | 9.99 | Robotshop | https://eu.robotshop.com/es/products/sensor-de-temperatura-y-humedad-dht22?qd=cb5eded7ee8b3a10f2775ecf068600a7
5 | PLA 1kg | 1 | €13.00 | 13 | Amazon | https://www.amazon.es/SUNLU-PLA-1-75mm-Pulcramente-Dimensional/dp/B0BTHSX6S3
6 | Mini Push Button Switch | 3 | €0.54 | 1.62 | Robotshop | https://eu.robotshop.com/es/products/mini-boton-interruptor?qd=ba865796dec8606c74620d6c79e11a55
7 | Squishy Circuits Switch | 1 | €5.58 | 5.58 | Robotshop | https://www.robotshop.com/products/squishy-circuits-switch?qd=39b0ae91ee1fd65d37b1df2a9d2177b2
8 | PCB - Placa de circuito impreso universal de doble cara (PCB, 9 x 15 cm, 10 unidades) | 1 | €10.17 | 10.17 € | Amazon | https://www.amazon.es/Unidades-Prototipos-Soldadura-Universal-Electr%C3%B3nica/dp/B07NWLGY3T
9 | DRV8825 Stepper Motor Driver (Header Pins Soldered) | 1 | €19,24 | 19.24 | Robotshop | https://eu.robotshop.com/products/drv8825-stepper-motor-driver-header-pins-soldered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
10 | RTC DS3231 | 1 | €4.50 | 4.5 | Amazon | https://www.amazon.es/WINGONEER-DS3231-AT24C32-precisi%C3%B3n-Arduino/dp/B01H5NAFUY
11 | SAI Mini UPS 6000 MAh | 1 | €39.90 | 39.9 | Amazon | https://www.amazon.es/Capacidad-Potencia-Alimentaci%C3%B3n-Ininterrumpida-Enrutador/dp/B0F6PC4MH5
12 | 3.5" LCD TFT Touch Display | 1 | €16.14 | 16.14 | Amazon | https://www.amazon.es/Binghe-Bol%C3%ADgrafo-Contacto-Resoluci%C3%B3n-Compatible/dp/B0D6B9M4ZH
13 |  |  |  | 0
14 |  |  |  | 0
15 |  |  |  | 0
16 |  |  |  | 0
17 |  |  |  | 0
18 |  |  |  | 0
19 |  |  |  | 0

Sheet: Recommended suppliers
Provider | Description | link
RS Online | distributor of electronics, electricity and industrial maintenance products | https://es.rs-online.com/
BCN 3D Technologies | 3D Printing Filament distributor for our 3D printer BCN 3D Sigma | https://www.bcn3dtechnologies.com/ca/
Robotshop | Stepper motor, grippers, servo motors, arduinos, raspberry Pi, drivers for motors | https://www.robotshop.com/
Motedis | Mechanical components, aluminium profiles | https://www.motedis.es/shop/index.php
Amazon | Electronics and more | https://www.amazon.es/
ALACER MAS | Mechanical components, aluminium profiles | http://www.alacermas.com/index.php
Please check also the list of recommended providers in the virtual campus.
https://campus.uvic.cat/aules/pluginfile.php/830007/mod_resource/content/2/IP2_List_of_possible_providers.pdf

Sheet: Calculations
MOTOR |  |  |  | DRY FOOD
 |  |  |  | For an adult cat (4-5kg)
Model Janssen
 |  |  |  | Cat needs | 250 | kcal/day | (High)
Dipòsit | Radi | 90 | mm | Dry food specs | 3.8 | kcal/g | (normal value)
 |  |  |  | Grams/day | 65.78947368 | g/day
Pinso | Densitat | 500 | kg/m^3 | Dry food qty | 3000 | g
 | Fricció | 0.4
K | Relació pressió lateral | 0.4 |  | Total days | 45.6 | days
Jansen | Tensió al fons | 783 | Pa
 | Força al fons | 19.9 | N
Parell motor
Cargol | Radi | 0.01 | m
Parell | Parell req | 0.199 | Nm
Motor | Parell fitxa tècnica | 0.4 | Nm
Security | SF | 2.010050251
POWER
Consum |  | V | Consum
 | NEMA 17 | 12 | 8-20 W
 | Driver | 5 | -
 | ESP32 | 5/3,3 | 20-80 mA
 | HX711 | 5 | <1,5 mA
 | DHT22 | 5
 | RTC | 5
Dispention
with limited motor and wifi not at highest power all de time
 | 12 V | 0,7 - 1,7 | A
 | 5 V | 0,1-0,3 | A
E total/dia |  | 0,73-2 | Wh/dia
Disable driver while not dispensing
Wifi only punctual

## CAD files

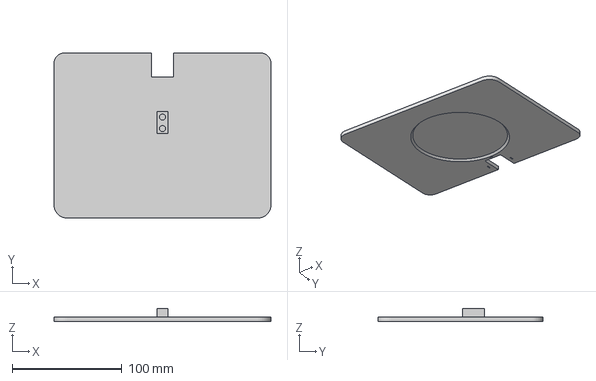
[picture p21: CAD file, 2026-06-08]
3D Parts/Bowl Plate.3mf
197.6 x 150.5 x 12.0 mm

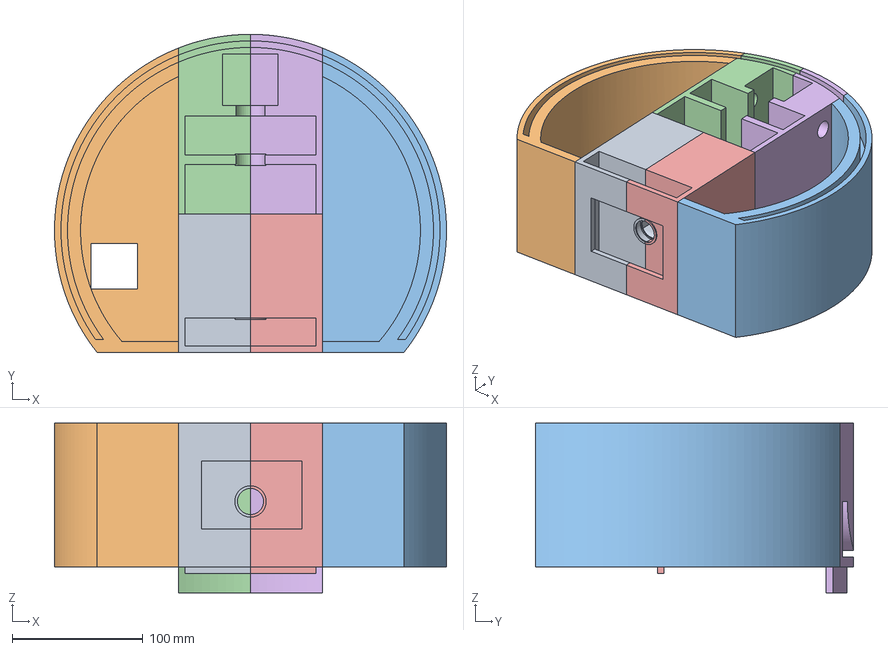
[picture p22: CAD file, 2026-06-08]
3D Parts/Central Part.3mf
299.9 x 243.5 x 130.0 mm
Cuerpo15
Cuerpo17
Cuerpo18
Cuerpo19
Cuerpo20
Cuerpo21

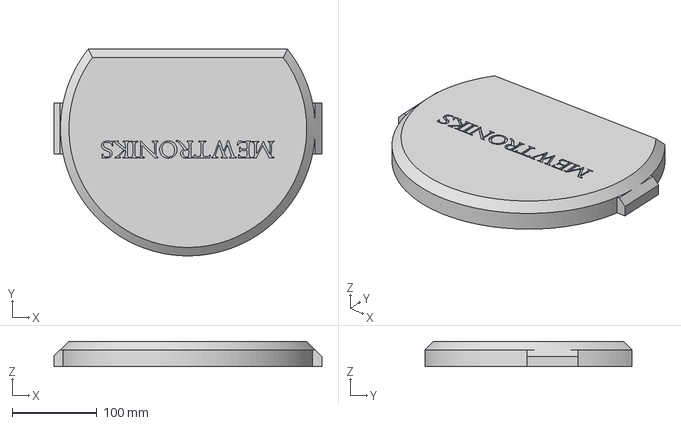
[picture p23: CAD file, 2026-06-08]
3D Parts/Top Cover.3mf
315.6 x 243.5 x 30.0 mm

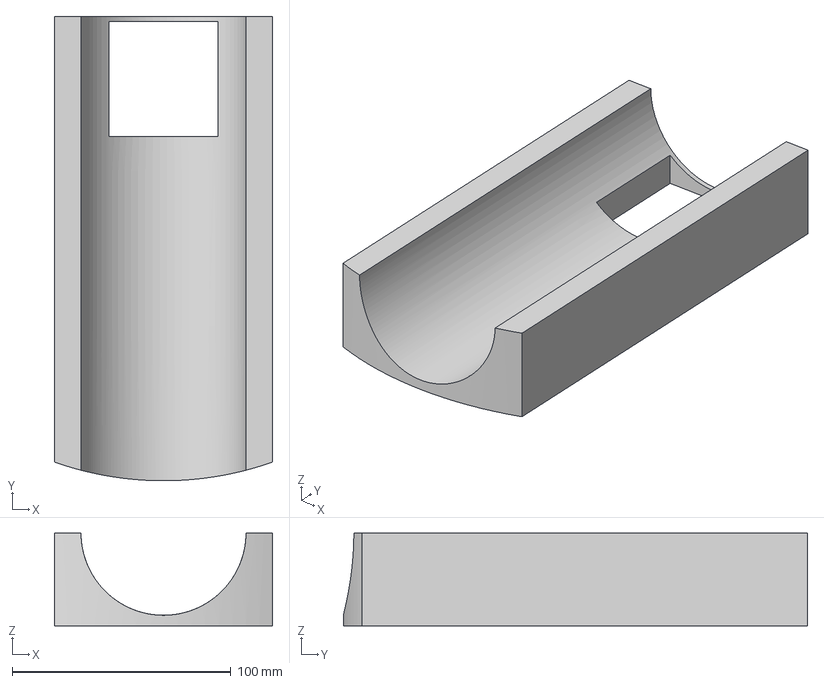
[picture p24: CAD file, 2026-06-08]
3D Parts/Cleaning Drawer.3mf
99.6 x 212.2 x 42.3 mm

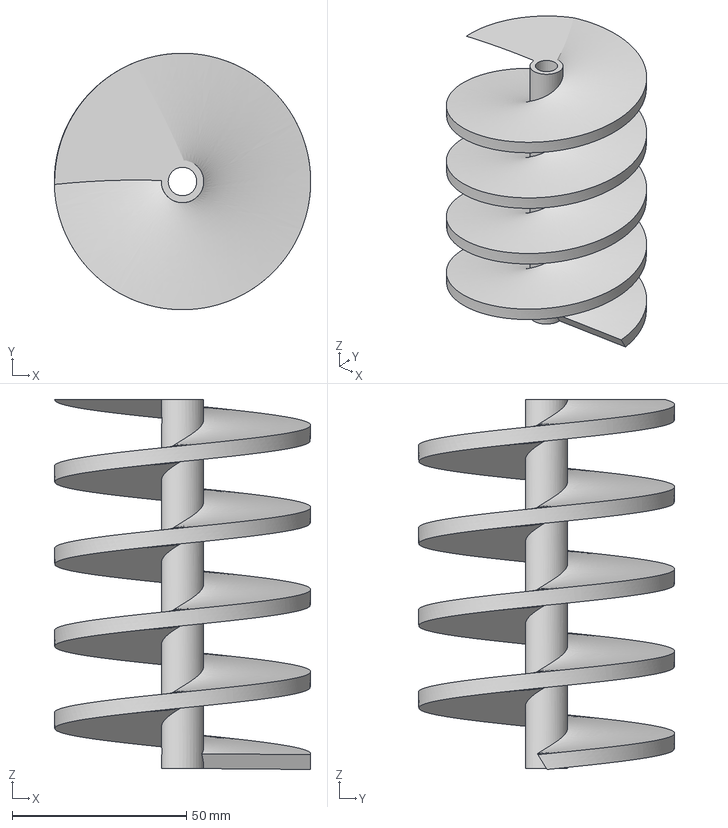
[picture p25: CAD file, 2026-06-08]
3D Parts/Helix.3mf
73.7 x 73.7 x 106.3 mm

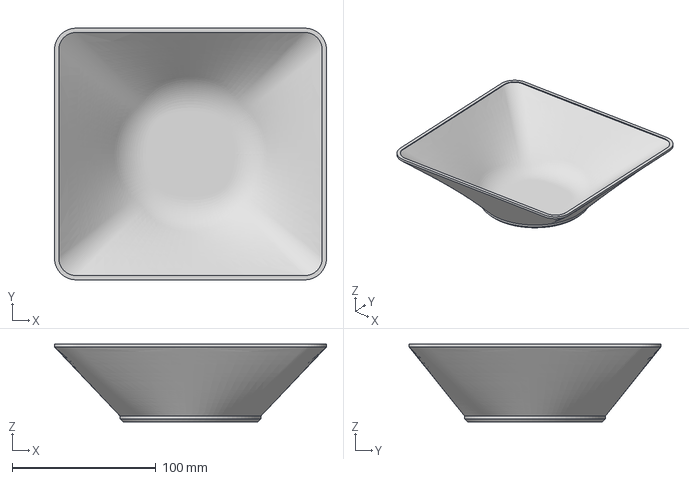
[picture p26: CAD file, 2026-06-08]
3D Parts/Bowl.3mf
189.1 x 175.0 x 54.0 mm

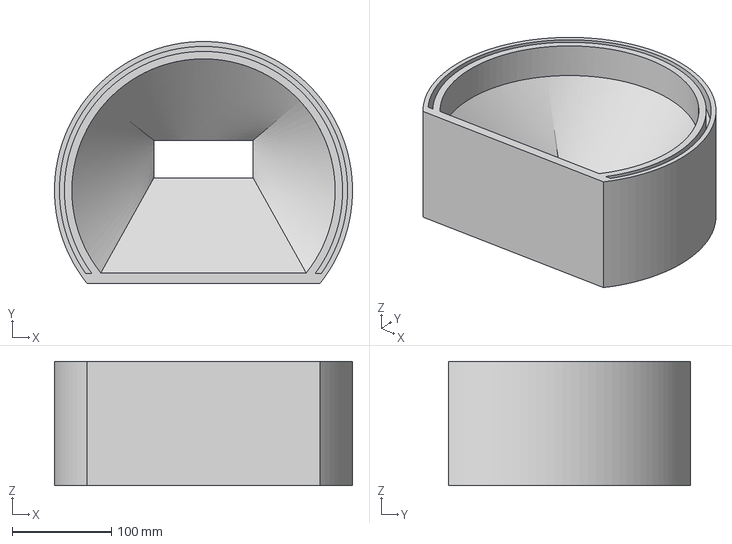
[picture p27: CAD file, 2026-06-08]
3D Parts/Hopper.3mf
299.9 x 243.5 x 125.0 mm

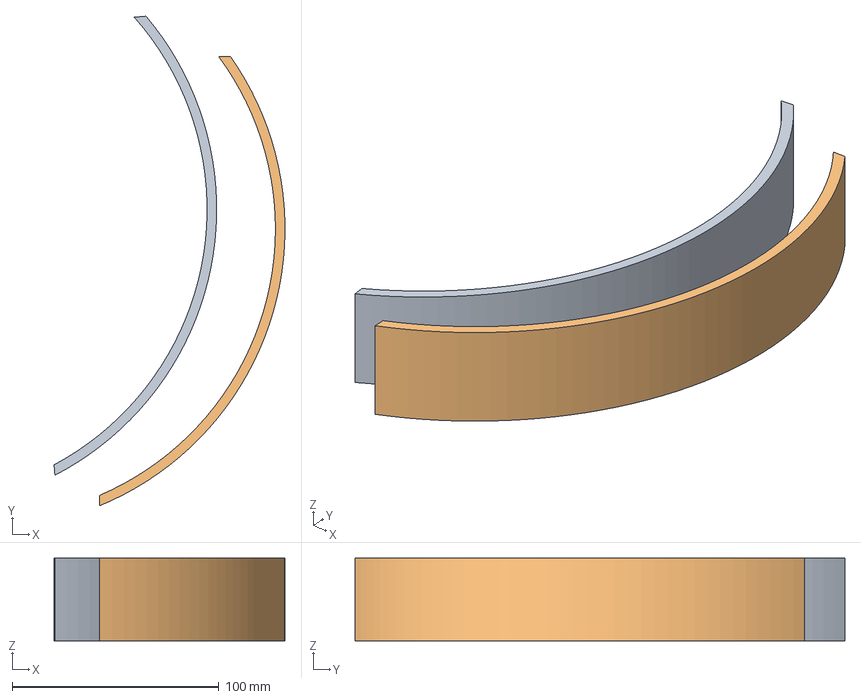
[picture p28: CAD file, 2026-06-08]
3D Parts/Join motor.3mf
111.7 x 236.8 x 40.0 mm
Cuerpo1
Cuerpo2

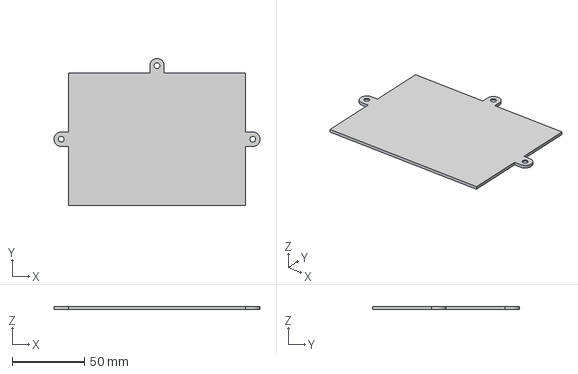
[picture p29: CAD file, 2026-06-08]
3D Parts/SAI Cover.3mf
142.8 x 101.8 x 2.00 mm

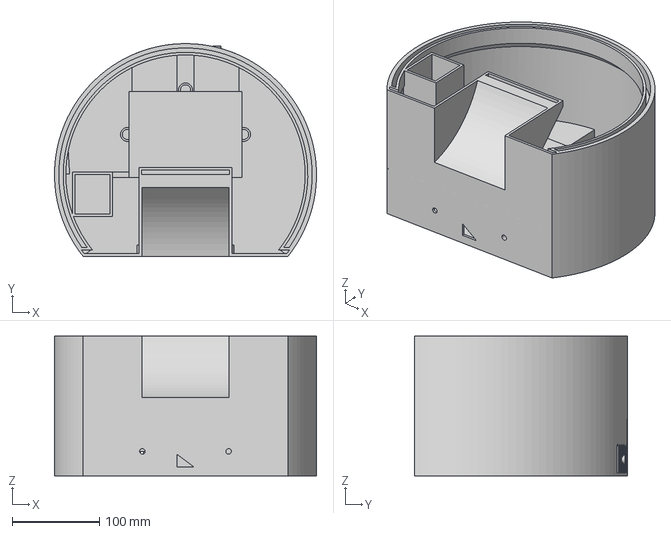
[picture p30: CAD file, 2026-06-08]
3D Parts/Base.3mf
299.9 x 243.6 x 160.0 mm

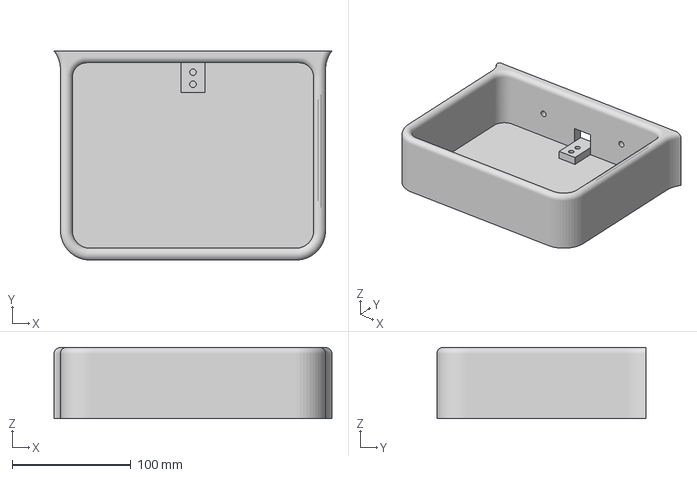
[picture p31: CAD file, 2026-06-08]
3D Parts/BowlBase.3mf
234.4 x 176.4 x 60.0 mm

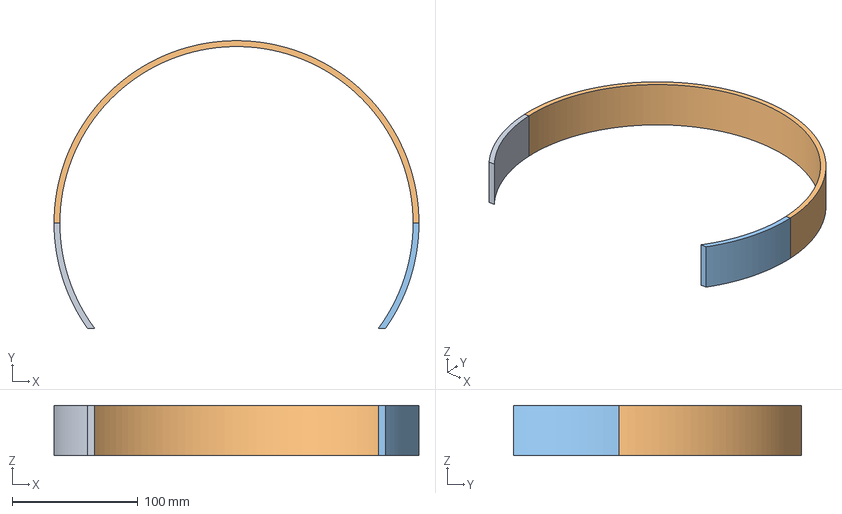
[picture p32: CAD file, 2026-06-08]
3D Parts/Join board.3mf
289.8 x 228.4 x 40.0 mm

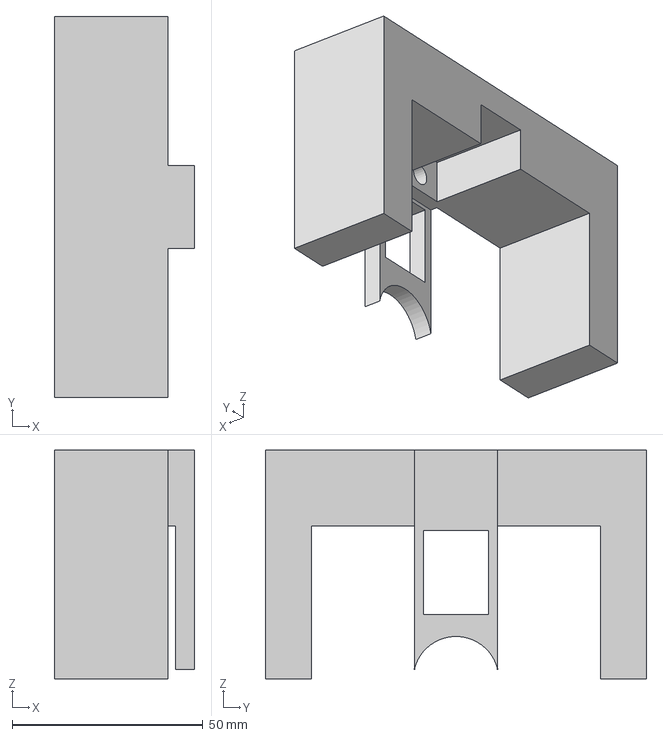
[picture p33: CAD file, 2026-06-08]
3D Parts/Support for humidity sensor.3mf
36.8 x 99.8 x 59.9 mm

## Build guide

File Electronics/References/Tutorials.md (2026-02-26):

---

# 📊 HX711 + Load Cell Integration

🔗 **Reference Tutorial:**  
https://www.hackster.io/mcmchris/diy-arduino-smart-digital-scale-esp8266-hx711-910945

This section documents the integration of the **HX711 24-bit ADC** with a **load cell** for precise weight measurement in the automatic cat feeder.

---

### 🛠 Hardware Connection

| Load Cell Wire | HX711 Pin | Notes |
|---|---|---|
| Red (VCC) | VCC | Excitation + |
| Black (GND) | GND | Excitation − |
| White (SIG−) | A− | Signal negative |
| Green (SIG+) | A+ | Signal positive |

> **Tip:** Use short, twisted pairs for the load cell wiring to minimize noise.

---

### 📌 HX711 Pinout to Microcontroller (ESP32 / Arduino)

| HX711 Pin | MCU Pin | Function |
|---|---|---|
| VCC | 3.3V | Power (use regulator) |
| GND | GND | Ground |
| DT | GPIO XX | Data output |
| SCK | GPIO YY | Serial clock |

> **Important:** Use the same ground for HX711 and microcontroller.

---

### 📐 Load Cell Calibration

To convert raw ADC counts into a weight:

1. Read raw HX711 value:
---
long reading = scale.read();

# 🛠 Stepper Motors with Arduino + A4988 / DRV8825 Drivers

🔗 **Reference Tutorial:**  
https://www.luisllamas.es/motores-paso-paso-arduino-driver-a4988-drv8825/

This section documents how to interface stepper motors with the Arduino (or ESP32) using **A4988** or **DRV8825** stepper motor drivers.

---

## 🎯 Pin Connections

### 📍 A4988 / DRV8825 to Microcontroller

| Driver Pin | Microcontroller | Function |
|---|---|---|
| **VMOT** | External Motor Power | Motor voltage supply |
| **GND** | GND | Common ground |
| **VDD** | 5V (logic) | Logic power |
| **STEP** | GPIO (e.g., 2) | Step signal |
| **DIR** | GPIO (e.g., 3) | Direction control |
| **EN** | GPIO / Pull-down | Enable driver |
| **MS1, MS2, MS3** | GPIO | Microstep configuration |

> **Note:** DRV8825 supports higher current and more microstepping options than A4988.

---
## 💻 Example Arduino Code

```cpp
#define STEP_PIN 2
#define DIR_PIN  3
#define EN_PIN   4

void setup() {
pinMode(STEP_PIN, OUTPUT);
pinMode(DIR_PIN, OUTPUT);
pinMode(EN_PIN, OUTPUT);

digitalWrite(EN_PIN, LOW); // Enable driver
digitalWrite(DIR_PIN, HIGH); // Set direction
}

void loop() {
digitalWrite(STEP_PIN, HIGH);
delayMicroseconds(800);
digitalWrite(STEP_PIN, LOW);
delayMicroseconds(800);
}

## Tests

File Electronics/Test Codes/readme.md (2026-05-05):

# Test Codes

This folder contains test programs used to validate the electronic components of the Automatic Cat Feeder project.

Each test is focused on checking one specific component or one small part of the system before integrating everything into the final firmware.

## Purpose

The purpose of these test codes is to:

- Verify that each component works correctly.
- Check the wiring and pin assignments.
- Validate sensor readings.
- Test actuator movement.
- Detect electrical or connection issues before full integration.
- Document the expected behaviour of each component.

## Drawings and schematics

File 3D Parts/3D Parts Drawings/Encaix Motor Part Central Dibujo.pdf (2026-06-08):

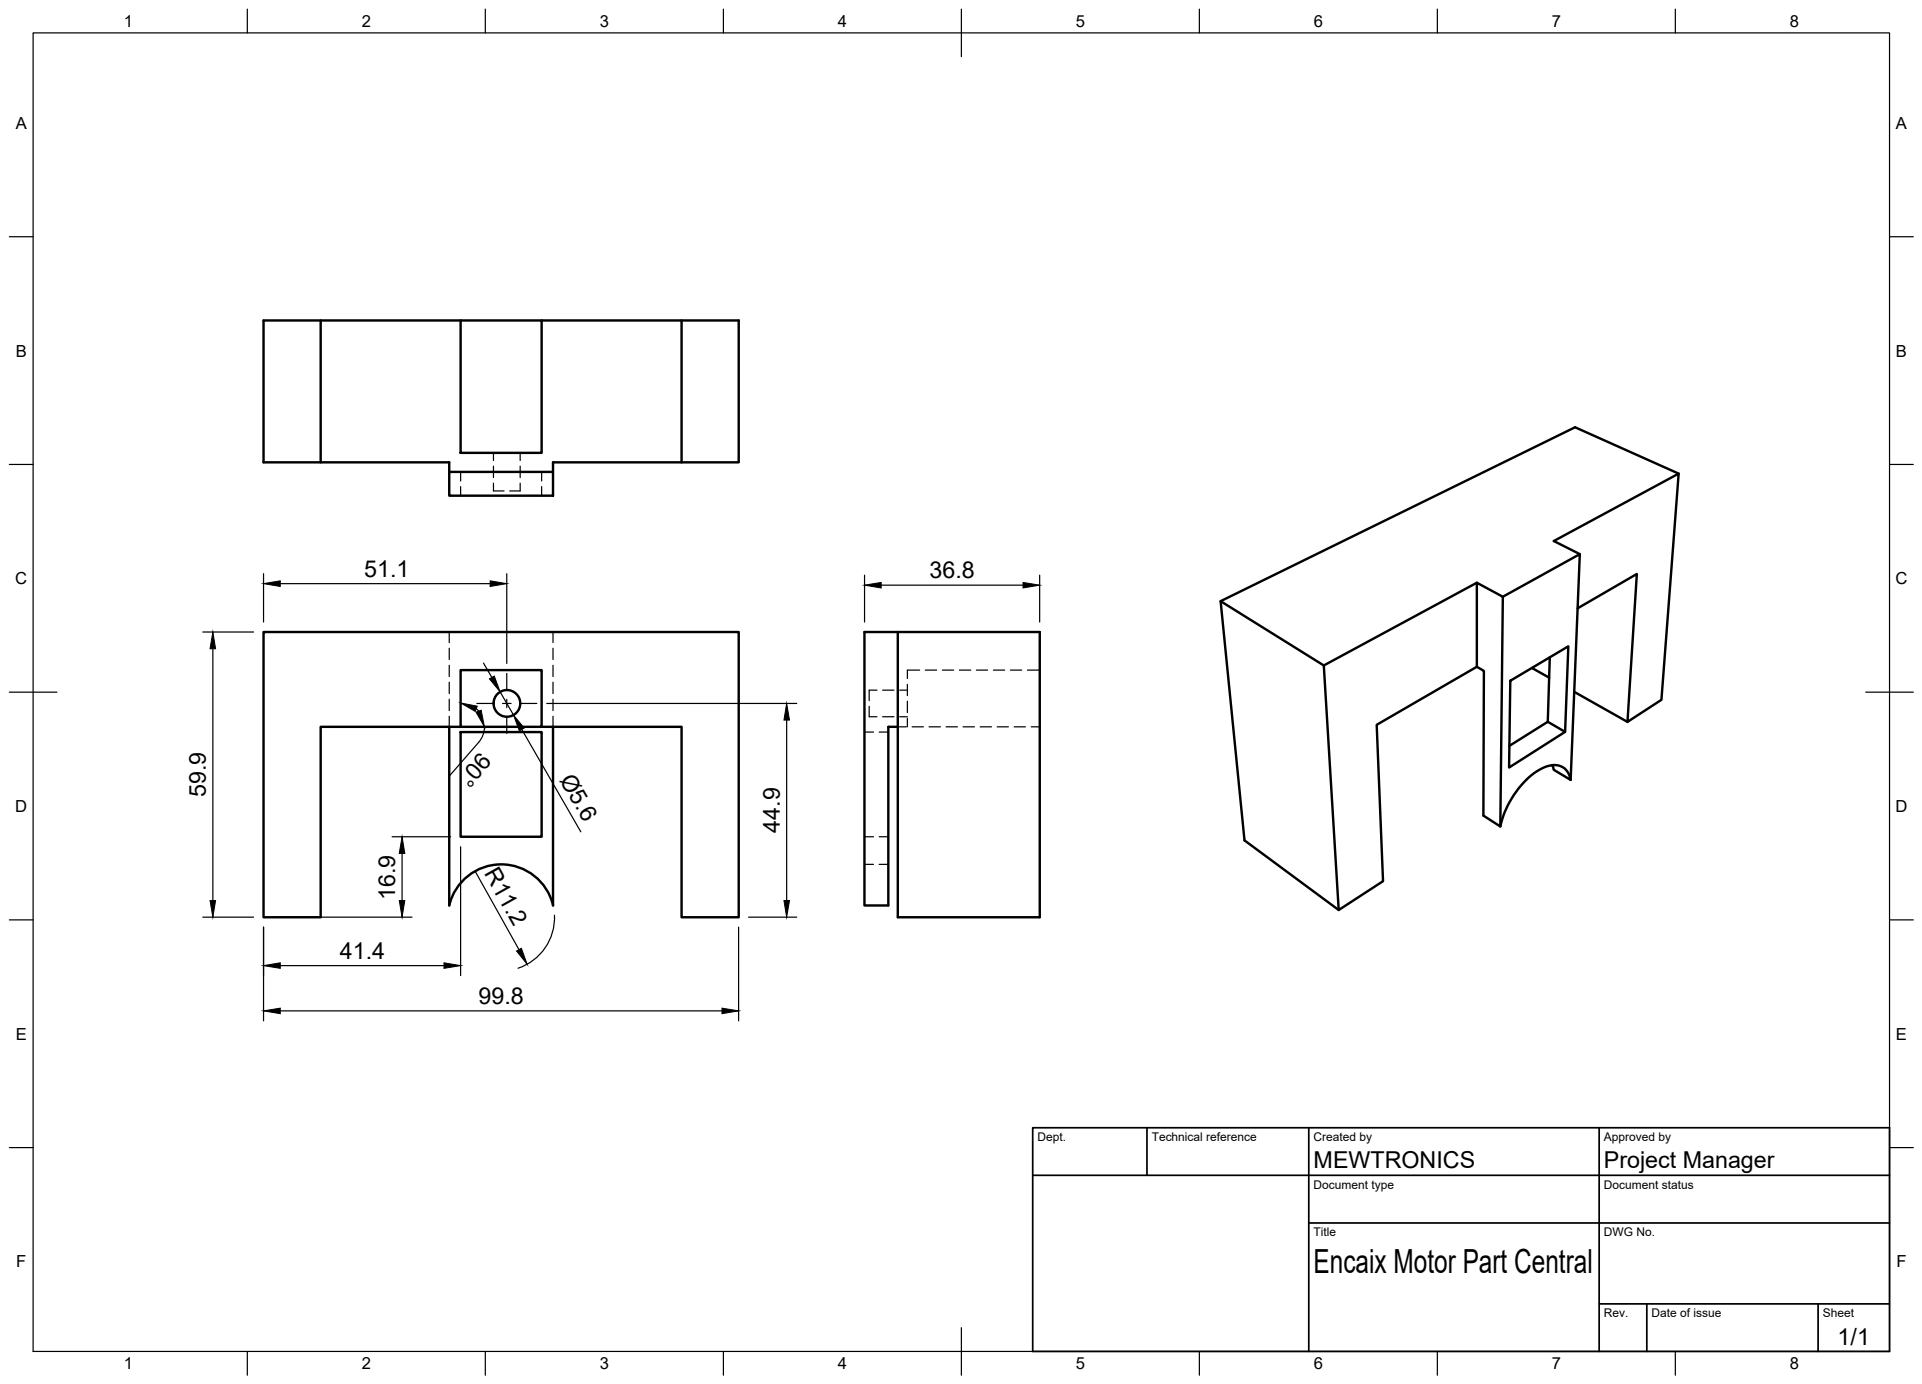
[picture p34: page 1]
Title; DWG No.; Rev.; Date of issue; Sheet

Dept. | Technical reference | Created by MEWTRONICS | Approved by Project Manager

Document type | Document status

Encaix Motor Part Central

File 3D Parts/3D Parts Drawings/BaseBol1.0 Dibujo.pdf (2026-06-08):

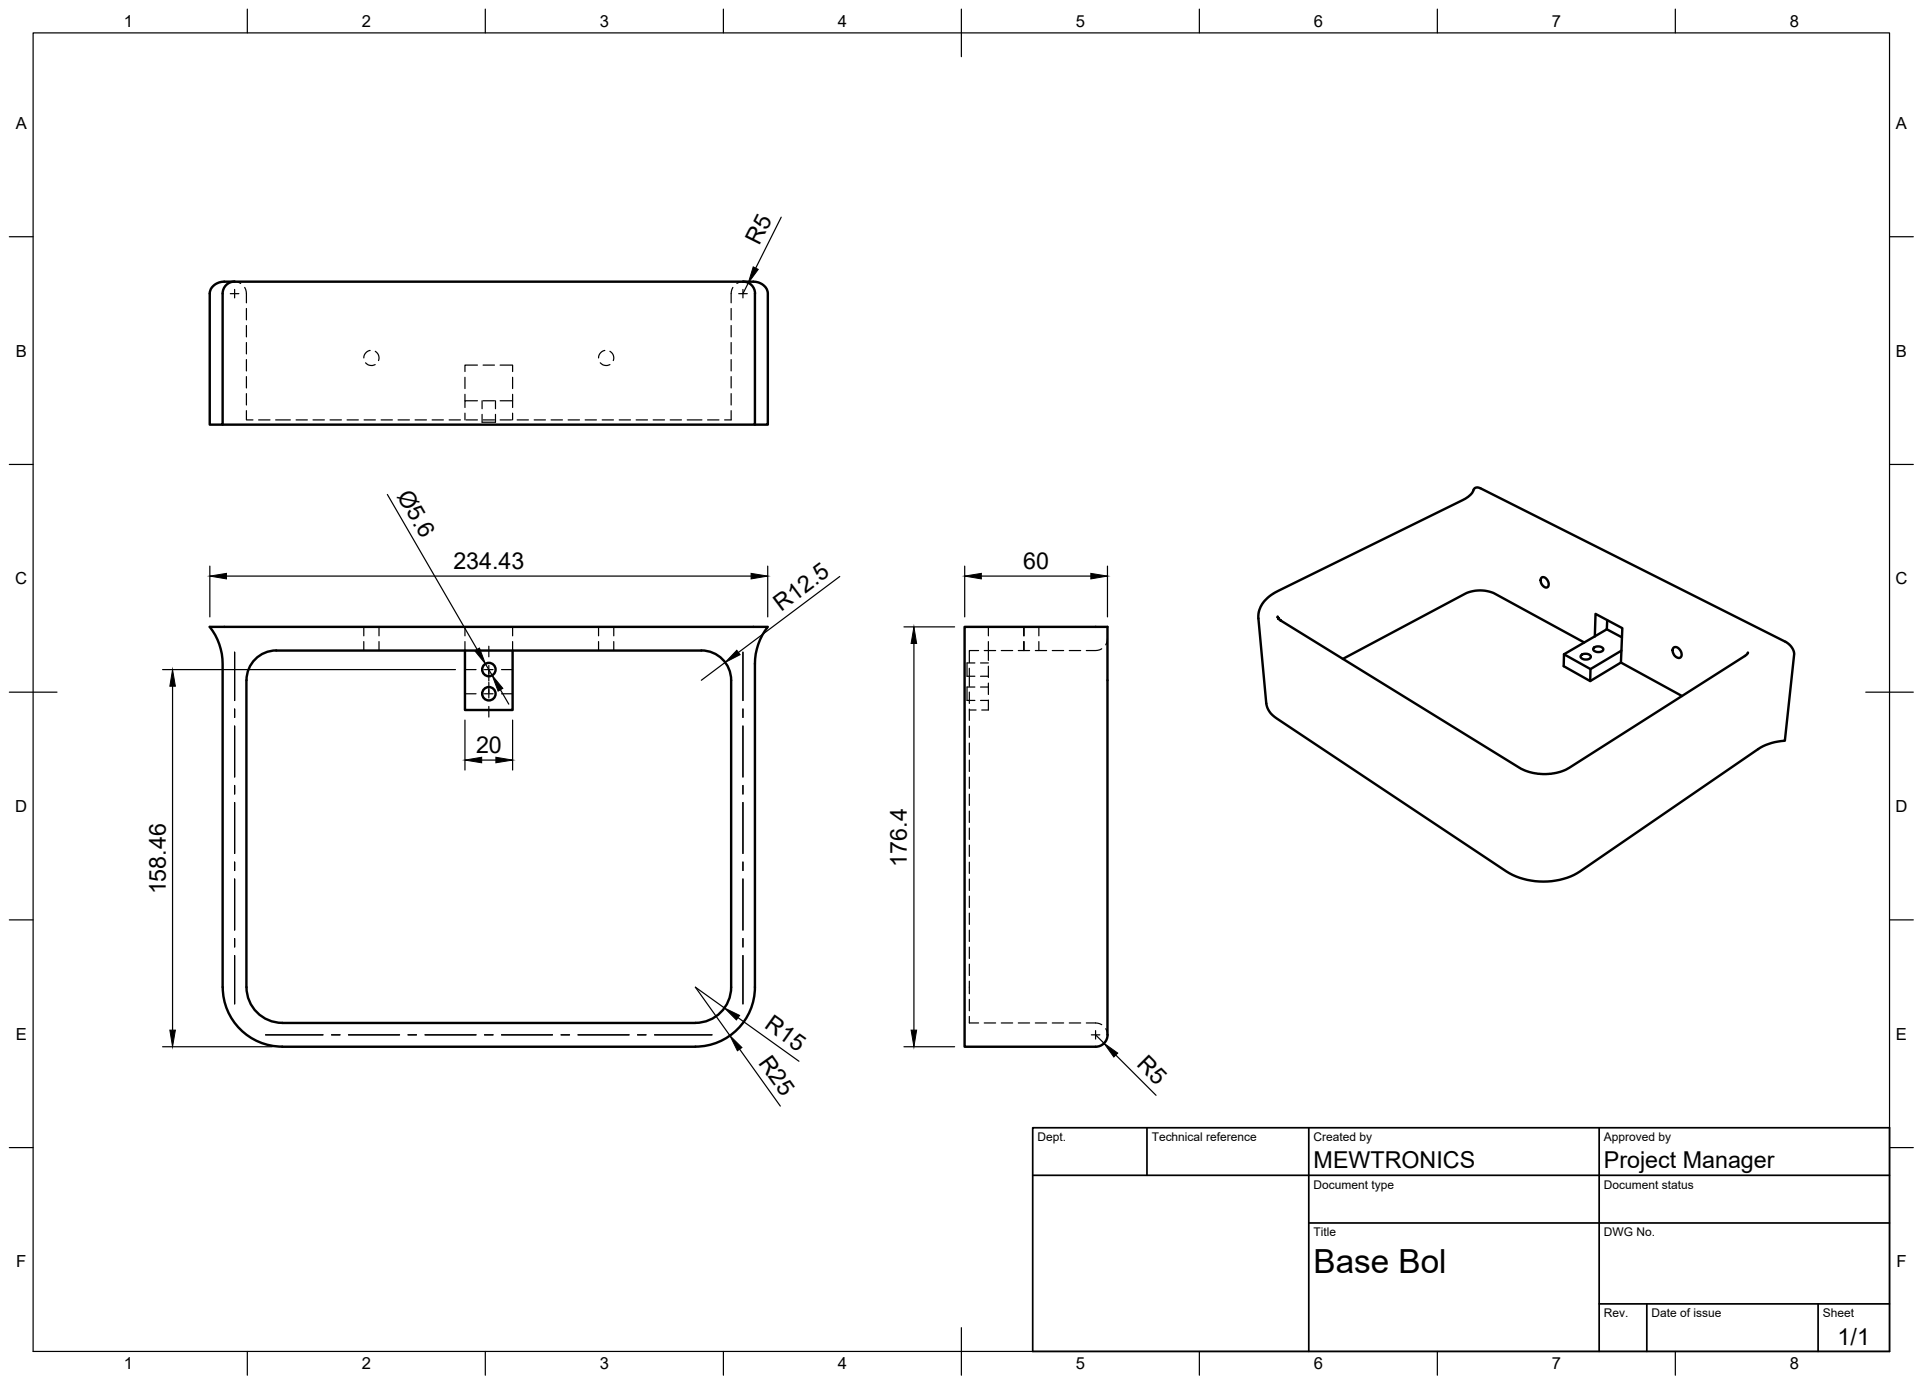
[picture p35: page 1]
Title; DWG No.; Rev.; Date of issue; Sheet; Base Bol

Dept. | Technical reference | Created by MEWTRONICS | Approved by Project Manager

Document type | Document status

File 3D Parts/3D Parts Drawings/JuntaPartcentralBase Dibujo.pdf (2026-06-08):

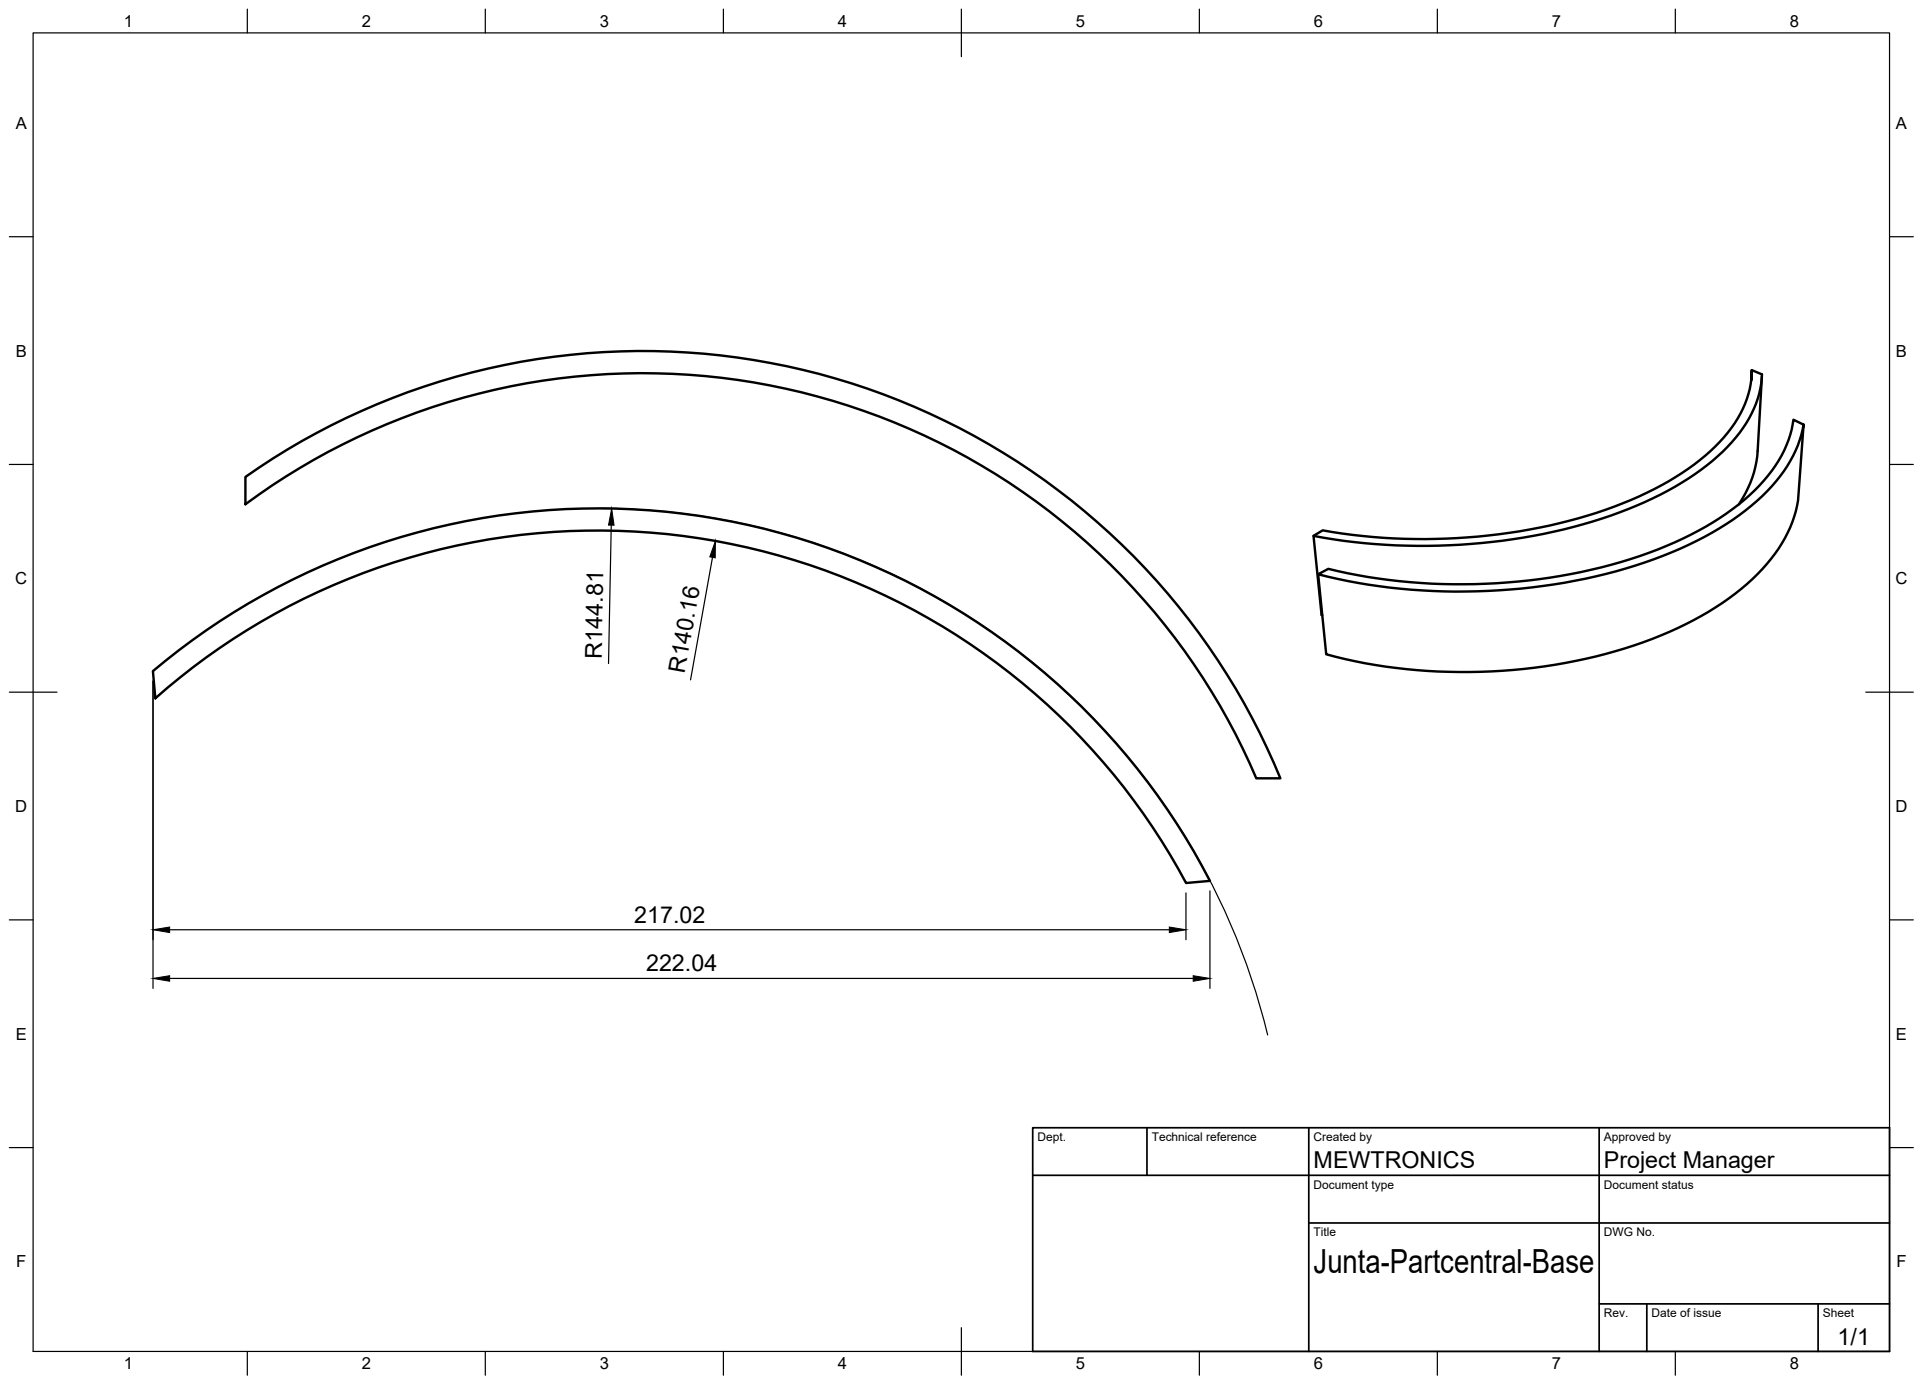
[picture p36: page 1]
Title; DWG No.; Rev.; Date of issue; Sheet; MEWTRONICS; Project Manager R144.81

Dept. | Technical reference | Created by | Approved by

Document type | Document status

Junta-Partcentral-Base

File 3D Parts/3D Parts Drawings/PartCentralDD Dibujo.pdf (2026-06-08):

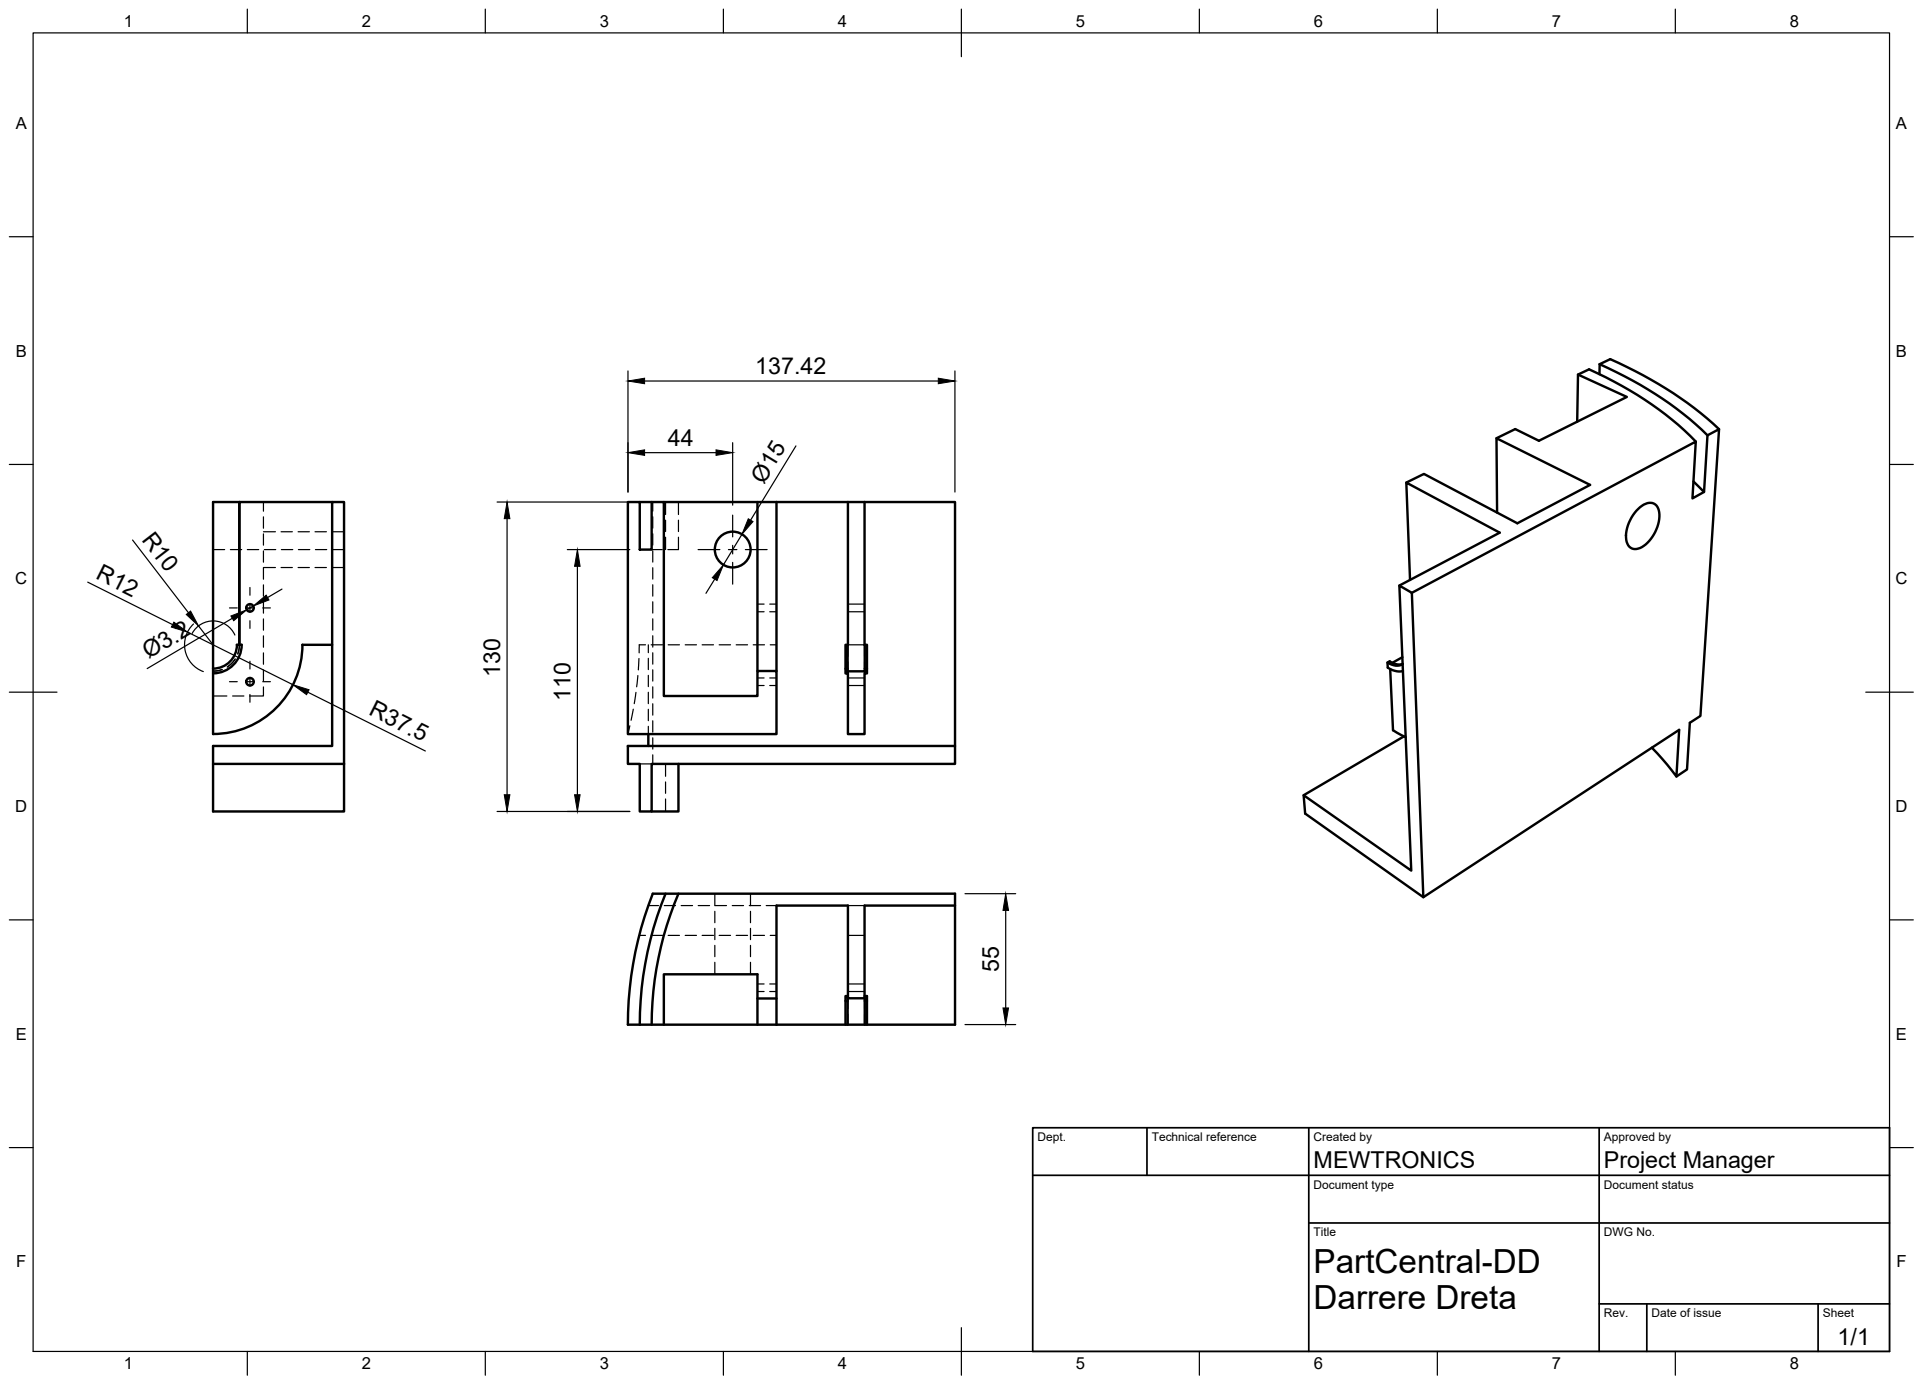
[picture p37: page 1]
Title; DWG No.; Rev.; Date of issue; Sheet; Darrere Dreta

Dept. | Technical reference | Created by MEWTRONICS | Approved by Project Manager

Document type | Document status

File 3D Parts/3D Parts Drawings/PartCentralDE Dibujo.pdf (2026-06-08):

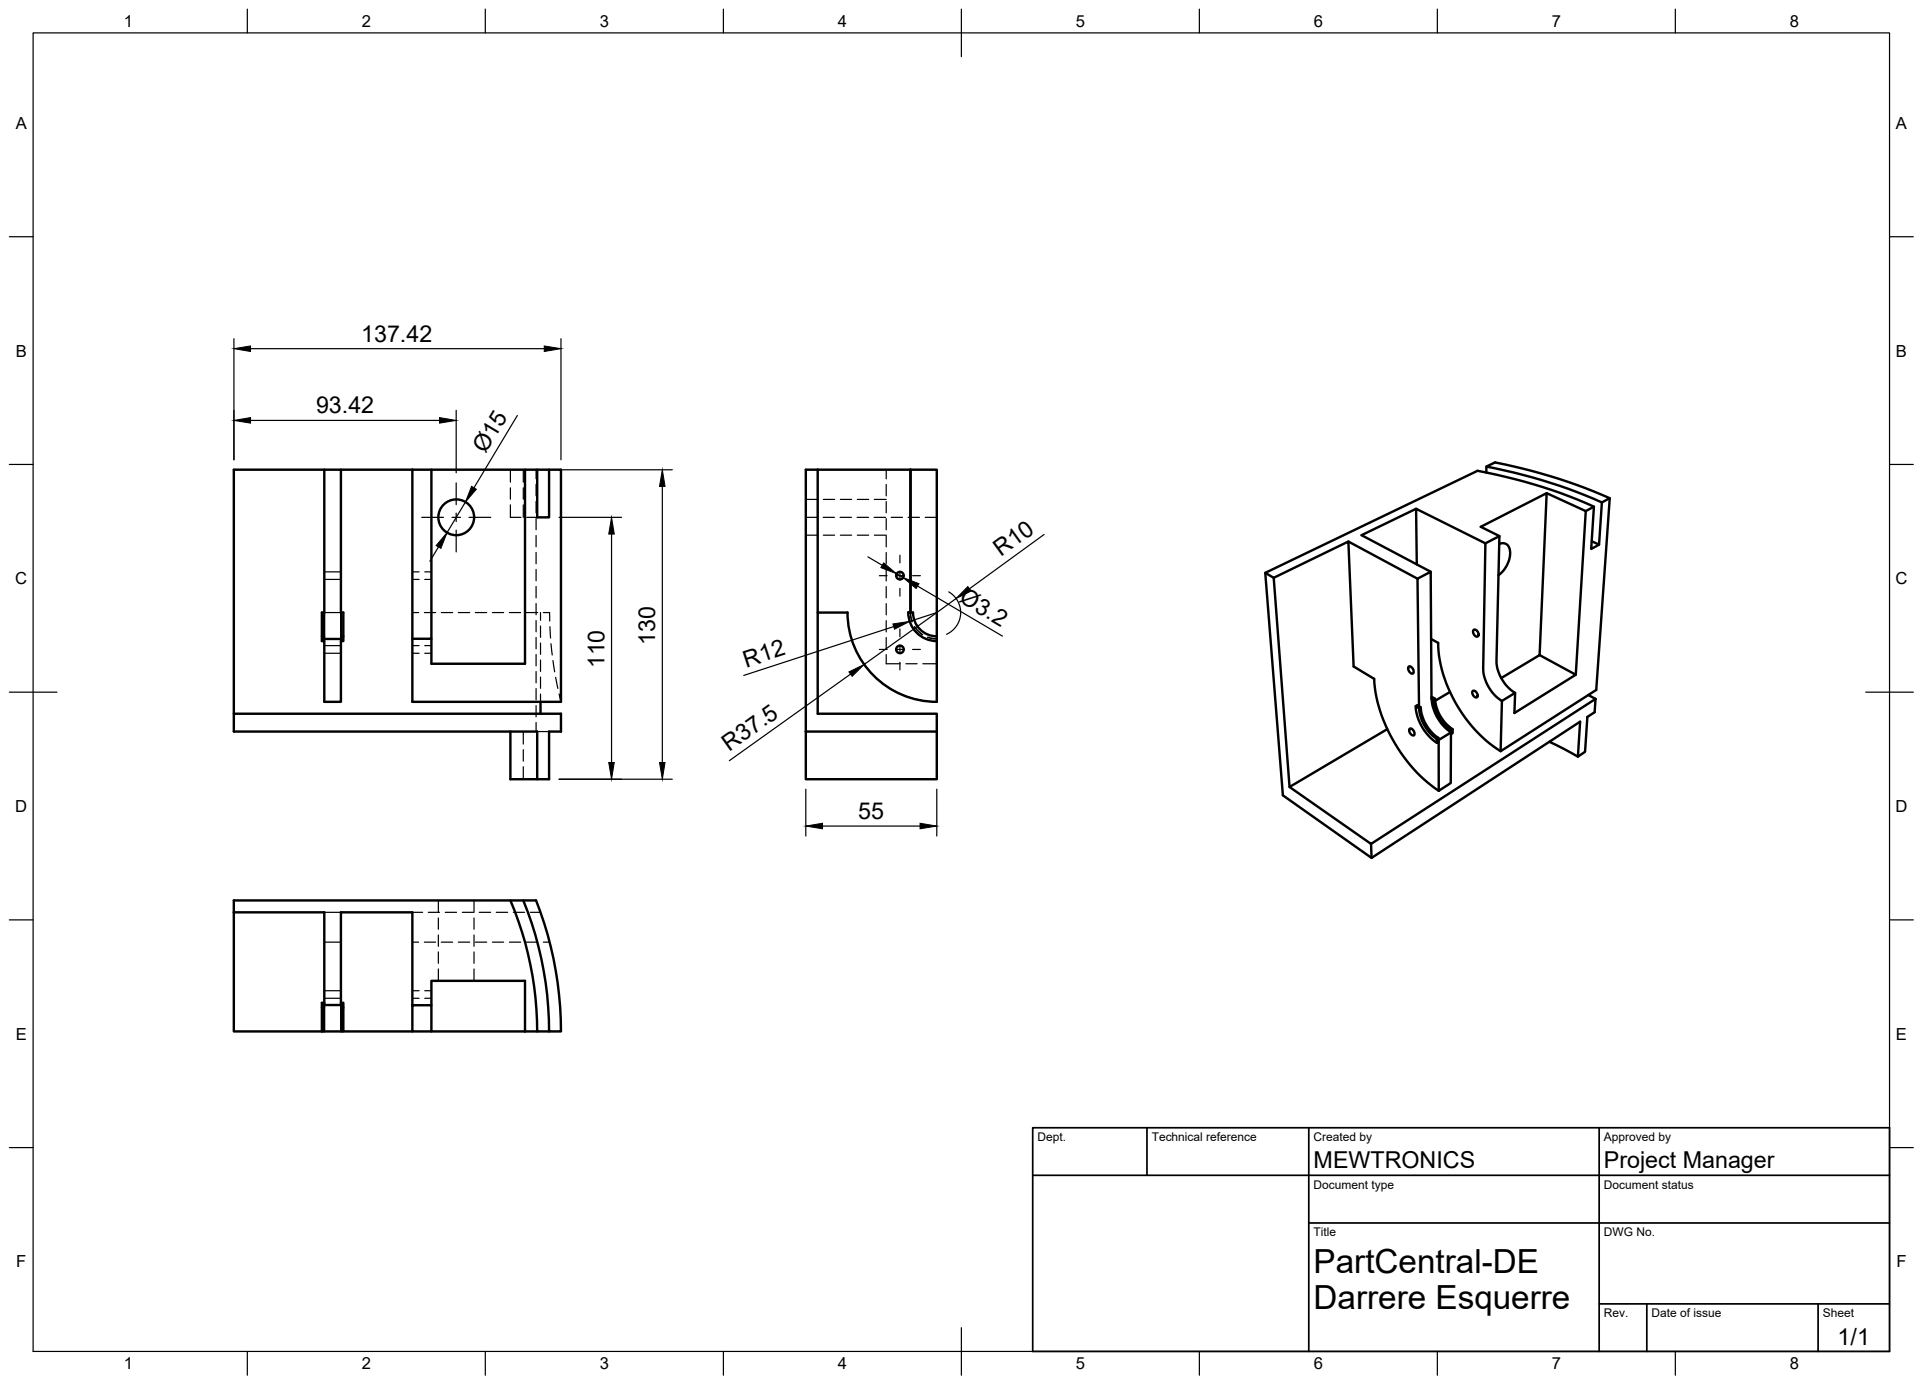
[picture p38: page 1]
Title; DWG No.; Rev.; Date of issue; Sheet; Darrere Esquerre

Dept. | Technical reference | Created by MEWTRONICS | Approved by Project Manager

Document type | Document status

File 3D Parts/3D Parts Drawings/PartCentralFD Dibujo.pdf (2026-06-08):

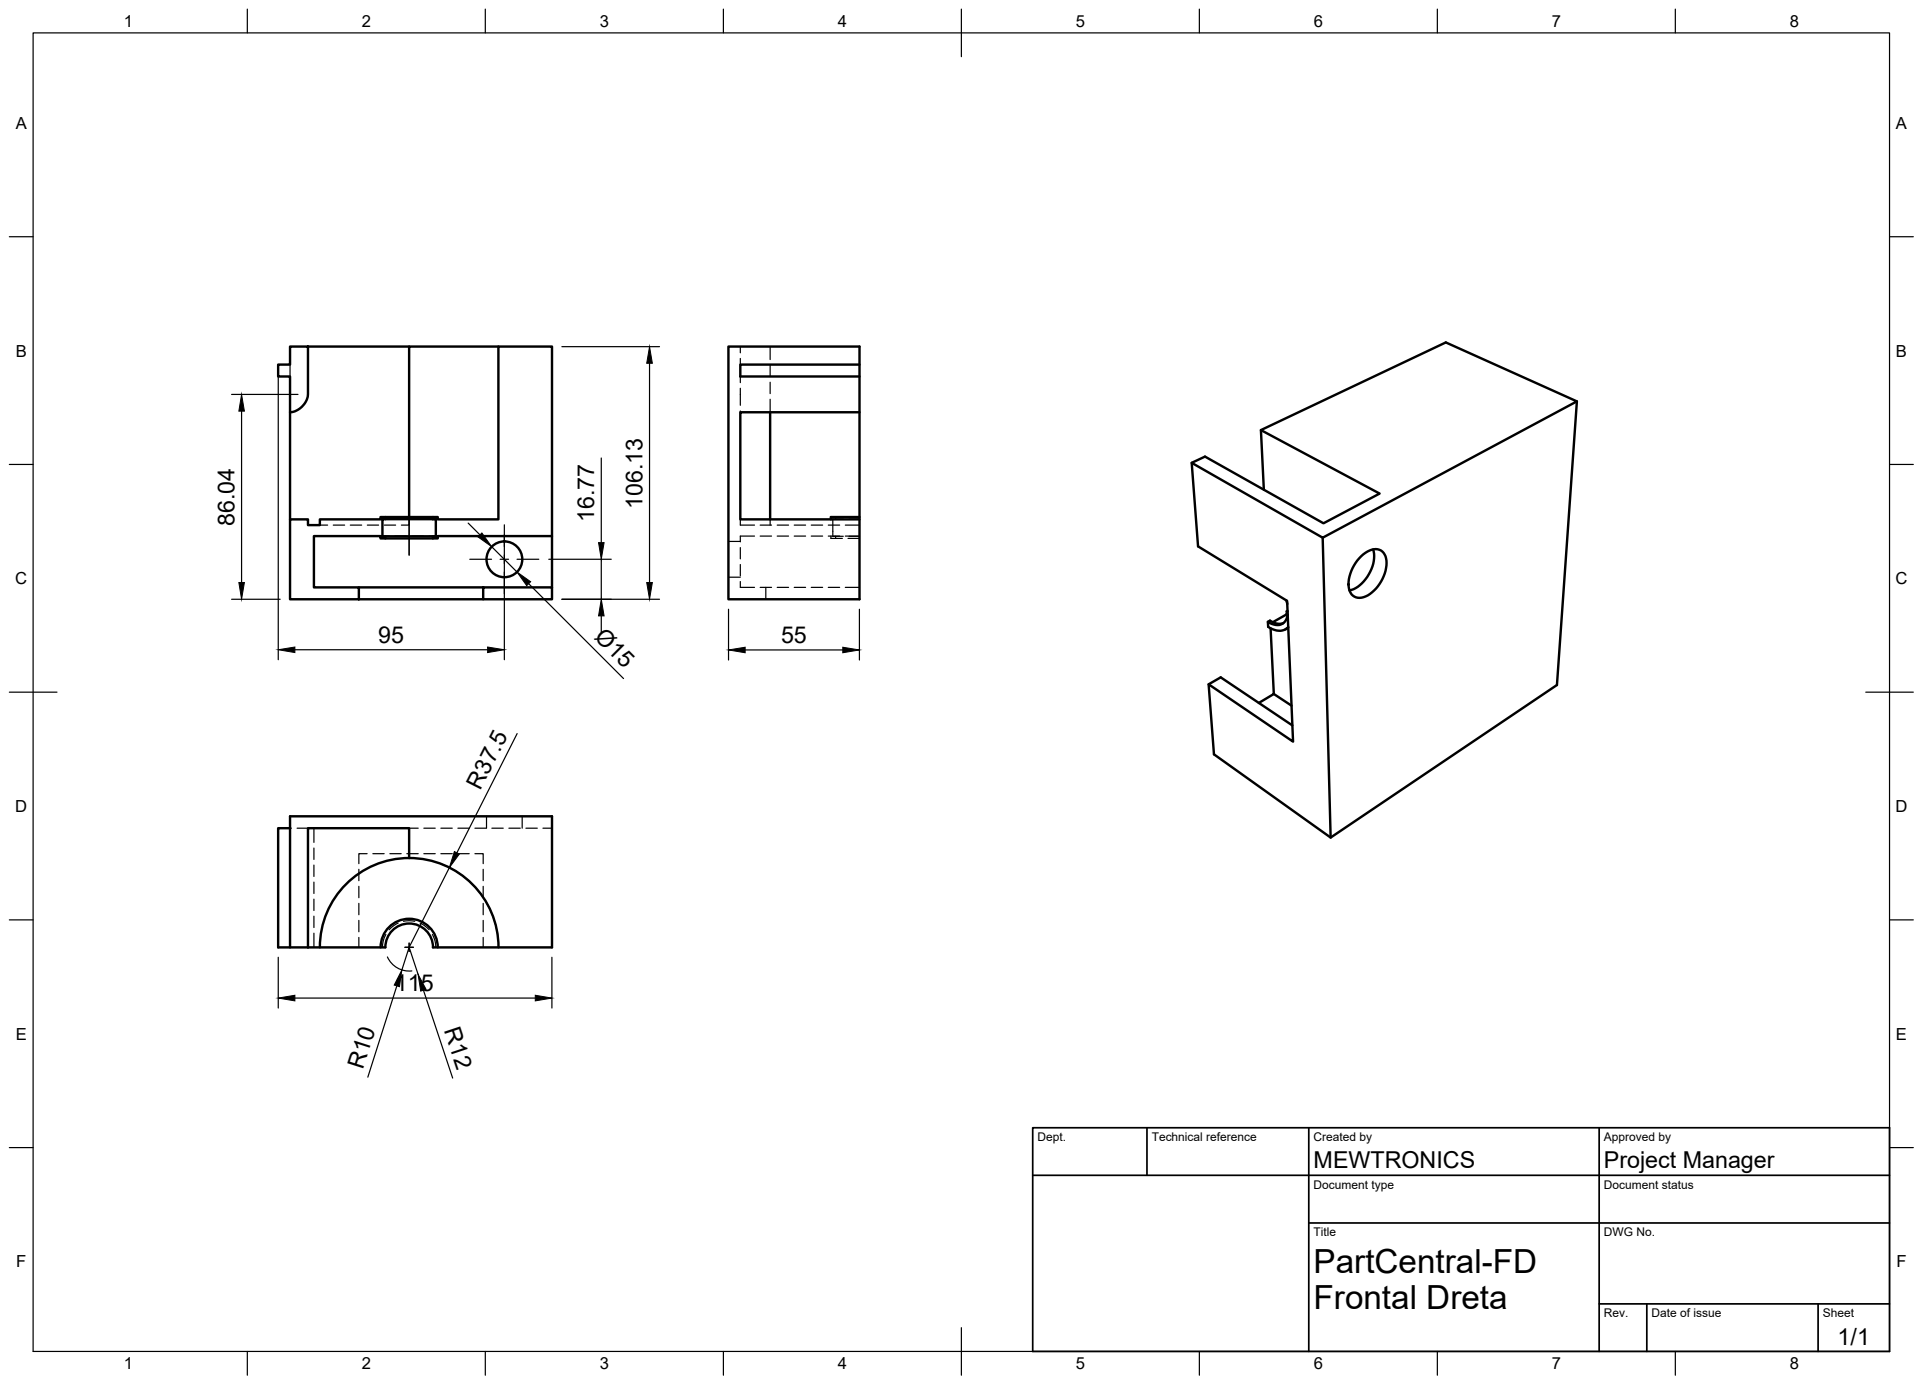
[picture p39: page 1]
Title; DWG No.; Rev.; Date of issue; Sheet; Frontal Dreta; MEWTRONICS; Project Manager 106.13

Dept. | Technical reference | Created by | Approved by

Document type | Document status

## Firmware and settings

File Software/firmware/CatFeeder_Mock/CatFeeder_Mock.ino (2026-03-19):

/*
 ============================================================
  CatFeeder Mock Firmware — ESP32 WROOM-32
  Integrated Project II · GR15 [GEMEC-09UV] · UVic-UCC
  Academic Year 2025-2026
 ============================================================
  PURPOSE:
    Simulates all hardware sensors and actuators of the smart
    cat feeder to allow full web-app testing WITHOUT physical
    hardware. Replace the simulation blocks with real sensor
    calls once the electronics are assembled.

  HARDWARE TO INTEGRATE LATER:
    - HX711 load cell ADC  (food weight)
    - DHT22 temperature & humidity sensor
    - DRV8825 stepper motor driver (auger motor)
    - Status LED
    - Optional: RFID RC522 for cat identification

  COMMUNICATION:
    - WiFi (STA mode) → internet or LAN
    - Supabase REST API over HTTPS (HTTPClient)
    - Polls device_config every 60 s
    - Posts heartbeat (devices table) every 30 s
    - Posts realtime_weight every 500 ms during dispensing
    - Polls commands table for pending commands

  DEPENDENCIES (install via Arduino Library Manager):
    - ArduinoJson  >= 7.x  (https://arduinojson.org)
    - WiFiClientSecure (built-in ESP32 Arduino core)
    - HTTPClient       (built-in ESP32 Arduino core)

  BOARD SETUP:
    - Board: "ESP32 Dev Module" (or WROOM-32)
    - Flash: 4 MB, Partition: Default
    - Upload speed: 115200

  USAGE:
    1. Fill in WIFI_SSID, WIFI_PASS, DEVICE_ID below.
    2. The SUPABASE_URL and SUPABASE_ANON_KEY match the webapp.
    3. Upload to ESP32, open Serial Monitor at 115200 baud.
 ============================================================
*/

#include <Arduino.h>
#include <ArduinoJson.h>
#include <HTTPClient.h>
#include <WiFi.h>
#include <WiFiClientSecure.h>

// ──────────────────────────────────────────────
//  USER CONFIGURATION — edit before uploading
// ──────────────────────────────────────────────
const char *WIFI_SSID = "Lab-Modul";
const char *WIFI_PASS = "GVe836Nf";

// Supabase project (matches webapp .env)
const char *SUPABASE_URL = "https://jawqxuzlvvzsrobftupx.supabase.co";
// ⚠️  IMPORTANT: Use the anon JWT key (NOT the publishable key
// sb_publishable_...).
//     The REST API requires a JWT in the Authorization header.
//     Get this from: Supabase Dashboard → Project → Settings → API →
//     anon/public
const char *SUPABASE_KEY =
    "eyJhbGciOiJIUzI1NiIsInR5cCI6IkpXVCJ9."
    "eyJpc3MiOiJzdXBhYmFzZSIsInJlZiI6Imphd3F4dXpsdnZ6c3JvYmZ0dXB4Iiwicm9sZSI6Im"
    "Fub24iLCJpYXQiOjE3NzM4NjY2MjcsImV4cCI6MjA4OTQ0MjYyN30."
    "FnvhOpqhZh9Z3j2XkIPla1wUbx3wAsaP4anr44Utrzs";

// Register a device in the webapp first, then paste the UUID here
const char *DEVICE_ID = "8a96c22a-1b29-47a8-8ca1-0f47e5aa2edd";

// ──────────────────────────────────────────────
//  SIMULATION PARAMETERS
// ──────────────────────────────────────────────
// Set to true to enable verbose serial logging
#define DEBUG_LOG true

// Simulated sensor noise bands
const float WEIGHT_NOISE_G = 1.5f; // ±g random variation per reading
const float TEMP_BASE_C = 23.0f;   // base ambient temperature
const float TEMP_NOISE_C = 0.8f;
const float HUM_BASE_PCT = 48.0f;
const float HUM_NOISE_PCT = 2.0f;

// Motor simulation
const float DISPENSE_RATE_G_S = 8.0f; // simulated grams per second dispensed

// ──────────────────────────────────────────────
//  GLOBAL STATE
// ──────────────────────────────────────────────
enum DeviceState {
  STATE_IDLE,
  STATE_DISPENSING,
  STATE_FAULT_MOTOR,
  STATE_FAULT_SENSOR
};

DeviceState g_state = STATE_IDLE;
float g_currentWeight = 0.0f;
float g_targetWeight = 0.0f;
float g_dispensedWeight = 0.0f;
String g_activeCmdId = "";
String g_activeCatId = "";
bool g_tarePending = false;
bool g_restartPending = false;

// Config from Supabase
int g_configVersion = -1;
float g_calibrationFactor = 1.0f;
int g_motorTimeout = 30;
float g_hopperCapacity = 2000.0f;

// Timers
unsigned long g_lastHeartbeat = 0;
unsigned long g_lastConfigPoll = 0;
unsigned long g_lastCmdPoll = 0;
unsigned long g_lastWeightPost = 0;
unsigned long g_dispenseStart = 0;

// Intervals (ms)
const unsigned long HEARTBEAT_INTERVAL = 30000;
const unsigned long CONFIG_INTERVAL = 60000;
const unsigned long CMD_POLL_INTERVAL = 5000;
const unsigned long WEIGHT_POST_INTERVAL = 500;

// ──────────────────────────────────────────────
//  UTILITY: random float in range
// ──────────────────────────────────────────────
float randRange(float lo, float hi) {
  return lo + (float)random(0, 10000) / 10000.0f * (hi - lo);
}

// ──────────────────────────────────────────────
//  SENSOR SIMULATION FUNCTIONS
//  → Replace these with real sensor reads later
// ──────────────────────────────────────────────

/**
 * readWeight() — simulates HX711 load cell reading
 *
 * REAL IMPLEMENTATION (replace this block):
 *   #include "HX711.h"
 *   HX711 scale;
 *   scale.begin(DOUT_PIN, CLK_PIN);
 *   scale.set_scale(g_calibrationFactor);
 *   return scale.get_units(5);
 */
float readWeight() {
  float noise = randRange(-WEIGHT_NOISE_G, WEIGHT_NOISE_G);
  return max(0.0f, g_currentWeight + noise);
}

/**
 * readTemperature() — simulates DHT22 temperature sensor
 *
 * REAL IMPLEMENTATION:
 *   #include "DHT.h"
 *   DHT dht(DHT_PIN, DHT22);
 *   return dht.readTemperature();
 */
float readTemperature() {
  return TEMP_BASE_C + randRange(-TEMP_NOISE_C, TEMP_NOISE_C);
}

/**
 * readHumidity() — simulates DHT22 humidity sensor
 *
 * REAL IMPLEMENTATION:
 *   return dht.readHumidity();
 */
float readHumidity() {
  return HUM_BASE_PCT + randRange(-HUM_NOISE_PCT, HUM_NOISE_PCT);
}

/**
 * setMotorRunning() — simulates DRV8825 stepper motor control
 *
 * REAL IMPLEMENTATION:
 *   digitalWrite(MOTOR_ENABLE_PIN, running ? LOW : HIGH);
 *   if (running) { step motor via STEP/DIR pins }
 */
void setMotorRunning(bool running) {
  if (DEBUG_LOG)
    Serial.printf("[MOTOR] %s\n", running ? "START" : "STOP");
  // TODO: digitalWrite(MOTOR_ENABLE_PIN, running ? LOW : HIGH);
}

/**
 * performTare() — simulates zeroing the scale
 *
 * REAL IMPLEMENTATION:
 *   scale.tare();
 */
void performTare() {
  g_currentWeight = 0.0f;
  g_dispensedWeight = 0.0f;
  if (DEBUG_LOG)
    Serial.println("[TARE] Scale zeroed");
  // TODO: scale.tare();
}

// ──────────────────────────────────────────────
//  HTTP HELPERS
// ──────────────────────────────────────────────
String buildUrl(const char *path) {
  return String(SUPABASE_URL) + "/rest/v1/" + path;
}

bool supabaseGet(const String &path, JsonDocument &out) {
  WiFiClientSecure client;
  client.setInsecure();
  HTTPClient http;
  http.begin(client, buildUrl(path.c_str()));
  http.addHeader("apikey", SUPABASE_KEY);
  http.addHeader("Authorization", String("Bearer ") + SUPABASE_KEY);
  http.addHeader("Content-Type", "application/json");
  http.addHeader("Accept", "application/json");

  int code = http.GET();
  String payload = http.getString();
  http.end();
  if (code == 200) {
    deserializeJson(out, payload);
    return true;
  }
  if (DEBUG_LOG)
    Serial.printf("[HTTP GET ERROR] %s → %d | %s\n", path.c_str(), code,
                  payload.c_str());
  return false;
}

bool supabasePost(const String &path, const String &body) {
  WiFiClientSecure client;
  client.setInsecure();
  HTTPClient http;
  http.begin(client, buildUrl(path.c_str()));
  http.addHeader("apikey", SUPABASE_KEY);
  http.addHeader("Authorization", String("Bearer ") + SUPABASE_KEY);
  http.addHeader("Content-Type", "application/json");
  http.addHeader("Prefer", "return=minimal");

  int code = http.POST(body);
  bool ok = (code >= 200 && code < 300);
  if (!ok && DEBUG_LOG) {
    Serial.printf("[HTTP POST ERROR] %s → %d\n  Body: %s\n  Resp: %s\n",
                  path.c_str(), code, body.c_str(), http.getString().c_str());
  } else if (DEBUG_LOG) {
    Serial.printf("[HTTP POST OK] %s → %d\n", path.c_str(), code);
  }
  http.end();
  return ok;
}

bool supabasePatch(const String &path, const String &body) {
  WiFiClientSecure client;
  client.setInsecure();
  HTTPClient http;
  http.begin(client, buildUrl(path.c_str()));
  http.addHeader("apikey", SUPABASE_KEY);
  http.addHeader("Authorization", String("Bearer ") + SUPABASE_KEY);
  http.addHeader("Content-Type", "application/json");
  http.addHeader("Prefer", "return=minimal");

  int code = http.PATCH(body);
  bool ok = (code >= 200 && code < 300);
  if (!ok && DEBUG_LOG) {
    Serial.printf("[HTTP PATCH ERROR] %s → %d\n  Body: %s\n  Resp: %s\n",
                  path.c_str(), code, body.c_str(), http.getString().c_str());
  } else if (DEBUG_LOG) {
    Serial.printf("[HTTP PATCH OK] %s → %d\n", path.c_str(), code);
  }
  http.end();
  return ok;
}

// ──────────────────────────────────────────────
//  SUPABASE OPERATIONS
// ──────────────────────────────────────────────

void postHeartbeat() {
  if (strlen(DEVICE_ID) < 10)
    return; // guard: no device ID
  String status;
  switch (g_state) {
  case STATE_IDLE:
    status = "idle";
    break;
  case STATE_DISPENSING:
    status = "dispensing";
    break;
  case STATE_FAULT_MOTOR:
    status = "fault_motor";
    break;
  case STATE_FAULT_SENSOR:
    status = "fault_sensor";
    break;
  }
  // Use a fixed reference epoch + millis() offset to approximate ISO time
  // For real hardware, use NTP: configTime(0,0,"pool.ntp.org") + getLocalTime()
  String body = "{\"status\":\"" + status +
                "\","
                "\"firmware_version\":\"mock-1.0.0\"}";
  supabasePatch(String("devices?id=eq.") + DEVICE_ID, body);
}

void postRealtimeWeight(float weight) {
  if (strlen(DEVICE_ID) < 10)
    return;
  String body = "{\"device_id\":\"" + String(DEVICE_ID) +
                "\","
                "\"weight_grams\":" +
                String(weight, 2) + "}";
  supabasePost("realtime_weight", body);
}

void postFeedEvent(float actual, const String &status,
                   const String &errCode = "") {
  if (strlen(DEVICE_ID) < 10)
    return;
  String body =
      "{\"device_id\":\"" + String(DEVICE_ID) +
      "\","
      "\"cat_id\":" +
      (g_activeCatId.length() ? "\"" + g_activeCatId + "\"" : String("null")) +
      ","
      "\"trigger_type\":\"manual\","
      "\"target_grams\":" +
      String(g_targetWeight, 1) +
      ","
      "\"actual_grams\":" +
      String(actual, 1) +
      ","
      "\"status\":\"" +
      status + "\"" +
      (errCode.length() ? ",\"error_code\":\"" + errCode + "\"" : String("")) +
      "}";
  supabasePost("feed_events", body);
}

void markCommandStatus(const String &cmdId, const String &status) {
  if (cmdId.length() < 10)
    return;
  String body = "{\"status\":\"" + status + "\"}";
  supabasePatch(String("commands?id=eq.") + cmdId, body);
}

void pollConfig() {
  if (strlen(DEVICE_ID) < 10)
    return;
  JsonDocument doc;
  if (!supabaseGet(
          String("device_config?device_id=eq.") + DEVICE_ID + "&limit=1", doc))
    return;
  if (doc.as<JsonArray>().size() == 0)
    return;

  JsonObject cfg = doc[0];
  int ver = cfg["config_version"] | 1;
  if (ver == g_configVersion)
    return; // no change

  g_configVersion = ver;
  g_calibrationFactor = cfg["calibration_factor"] | 1.0f;
  g_motorTimeout = cfg["motor_timeout_seconds"] | 30;
  g_hopperCapacity = cfg["hopper_capacity_grams"] | 2000.0f;
  bool tareTrigger = cfg["tare_trigger"] | false;

  if (tareTrigger)
    g_tarePending = true;

  if (DEBUG_LOG)
    Serial.printf("[CONFIG] v%d loaded · cal=%.4f · timeout=%ds\n",
                  g_configVersion, g_calibrationFactor, g_motorTimeout);
}

void pollCommands() {
  if (strlen(DEVICE_ID) < 10)
    return;
  if (g_state == STATE_DISPENSING)
    return; // busy — skip

  JsonDocument doc;
  String path = String("commands?device_id=eq.") + DEVICE_ID +
                "&status=eq.pending&order=created_at.asc&limit=1";
  if (!supabaseGet(path, doc))
    return;
  if (doc.as<JsonArray>().size() == 0)
    return;

  JsonObject cmd = doc[0];
  String cmdId = cmd["id"].as<String>();
  String cmdType = cmd["command_type"].as<String>();

  if (DEBUG_LOG)
    Serial.printf("[CMD] Received: %s (id=%s)\n", cmdType.c_str(),
                  cmdId.c_str());

  if (cmdType == "feed") {
    float portion = cmd["portion_grams"] | 50.0f;
    g_activeCatId = cmd["cat_id"].as<String>();
    g_activeCmdId = cmdId;
    g_targetWeight = portion;
    g_dispensedWeight = 0.0f;
    g_dispenseStart = millis();
    g_state = STATE_DISPENSING;
    setMotorRunning(true);
    Serial.printf("[DISPENSE] Starting: %.1fg for cat %s\n", portion,
                  g_activeCatId.c_str());

  } else if (cmdType == "tare") {
    performTare();
    markCommandStatus(cmdId, "completed");

  } else if (cmdType == "restart") {
    markCommandStatus(cmdId, "completed");
    Serial.println("[RESTART] Restarting in 2s…");
    delay(2000);
    ESP.restart();
  }
}

// ──────────────────────────────────────────────
//  DISPENSING SIMULATION LOOP
// ──────────────────────────────────────────────
void updateDispensing() {
  float elapsed = (millis() - g_dispenseStart) / 1000.0f;
  g_dispensedWeight = min(g_targetWeight, elapsed * DISPENSE_RATE_G_S);
  g_currentWeight = g_dispensedWeight;

  // Check motor timeout (safety limit)
  if (elapsed > g_motorTimeout) {
    Serial.println("[FAULT] Motor timeout exceeded!");
    setMotorRunning(false);
    postFeedEvent(g_dispensedWeight, "partial", "motor_timeout");
    markCommandStatus(g_activeCmdId, "error");
    g_state = STATE_FAULT_MOTOR;
    return;
  }

  // Check if target reached (within 1g tolerance)
  if (g_dispensedWeight >= g_targetWeight - 0.5f) {
    setMotorRunning(false);
    float actual = g_dispensedWeight + randRange(-0.5f, 0.5f);
    Serial.printf("[DISPENSE] Complete! Dispensed: %.1fg (target %.1fg)\n",
                  actual, g_targetWeight);
    postFeedEvent(actual, "completed");
    markCommandStatus(g_activeCmdId, "completed");
    g_state = STATE_IDLE;
    g_activeCmdId = "";
  }
}

// ──────────────────────────────────────────────
//  SETUP
// ──────────────────────────────────────────────
void setup() {
  Serial.begin(115200);
  delay(500);

  Serial.println("\n╔══════════════════════════════════╗");
  Serial.println("║  CatFeeder Mock Firmware v1.0.0  ║");
  Serial.println("║  ESP32 WROOM-32  ·  GR15 UVic    ║");
  Serial.println("╚══════════════════════════════════╝\n");

  // WiFi connection
  Serial.printf("[WiFi] Connecting to %s…\n", WIFI_SSID);
  WiFi.mode(WIFI_STA);
  WiFi.begin(WIFI_SSID, WIFI_PASS);

  int tries = 0;
  while (WiFi.status() != WL_CONNECTED && tries < 40) {
    delay(500);
    Serial.print(".");
    tries++;
  }

  if (WiFi.status() == WL_CONNECTED) {
    Serial.printf("\n[WiFi] Connected! IP: %s\n",
                  WiFi.localIP().toString().c_str());
  } else {
    Serial.println("\n[WiFi] FAILED — running in offline simulation mode");
  }

  randomSeed(analogRead(36)); // use floating pin for entropy

  // Initial data load
  if (WiFi.status() == WL_CONNECTED) {
    pollConfig();
    postHeartbeat();
  }

  Serial.println("[SETUP] Ready. Polling Supabase every 5s for commands.");
}

// ──────────────────────────────────────────────
//  MAIN LOOP
// ──────────────────────────────────────────────
void loop() {
  unsigned long now = millis();

  // ── WiFi reconnect guard ──
  if (WiFi.status() != WL_CONNECTED) {
    Serial.println("[WiFi] Reconnecting…");
    WiFi.reconnect();
    delay(5000);
    return;
  }

  // ── Heartbeat ──
  if (now - g_lastHeartbeat >= HEARTBEAT_INTERVAL) {
    g_lastHeartbeat = now;
    postHeartbeat();
  }

  // ── Config poll ──
  if (now - g_lastConfigPoll >= CONFIG_INTERVAL) {
    g_lastConfigPoll = now;
    pollConfig();
  }

  // ── Command poll ──
  if (now - g_lastCmdPoll >= CMD_POLL_INTERVAL) {
    g_lastCmdPoll = now;
    pollCommands();
  }

  // ── Dispensing update ──
  if (g_state == STATE_DISPENSING) {
    updateDispensing();

    // Post live weight every 500 ms
    if (now - g_lastWeightPost >= WEIGHT_POST_INTERVAL) {
      g_lastWeightPost = now;
      float w = readWeight();
      postRealtimeWeight(w);
      if (DEBUG_LOG)
        Serial.printf("[WEIGHT] %.2fg\n", w);
    }
  }

  // ── Tare pending ──
  if (g_tarePending) {
    performTare();
    g_tarePending = false;
    // Update config to clear tare_trigger flag
    if (strlen(DEVICE_ID) >= 10) {
      supabasePatch(String("device_config?device_id=eq.") + DEVICE_ID,
                    "{\"tare_trigger\":false}");
    }
  }

  // ── Fault recovery: auto-clear motor fault after 60s ──
  if (g_state == STATE_FAULT_MOTOR && now - g_dispenseStart > 60000) {
    Serial.println("[FAULT] Auto-recovering from motor fault");
    g_state = STATE_IDLE;
  }

  // ── Serial debug info (and idle weight post) every 10s ──
  static unsigned long lastPrint = 0;
  if (now - lastPrint >= 10000) {
    lastPrint = now;
    float temp = readTemperature();
    float hum = readHumidity();
    float w = readWeight();
    Serial.printf("[SYS] State=%d | Weight=%.1fg | Temp=%.1f°C | Hum=%.1f%%\n",
                  (int)g_state, w, temp, hum);

    // Post weight so the web app shows it even when idle
    if (g_state != STATE_DISPENSING) {
      postRealtimeWeight(w);
    }
  }

  delay(50); // small yield to prevent WDT issues
}

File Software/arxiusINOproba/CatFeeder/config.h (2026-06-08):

#ifndef CONFIG_H
#define CONFIG_H

#include <Arduino.h>
#include <TFT_eSPI.h>

extern TFT_eSPI tft;

// ==========================================================================
// CatFeeder — Global Configuration
// Integrated Project II — GR15 [GEMEC-09UV]
// ==========================================================================
// Pin map matches the REAL soldered hardware (see project doc T5).
// ESP32 WROOM-32 + ILI9341 2.8" 320x240 (XPT2046 touch, shared SPI bus)
// HX711 load cell, DHT22, NEMA17 + DRV8825.
// DS3231 RTC removed to avoid I2C conflicts with the touch controller.
// NO physical buttons — the only user interface is the touch screen.
// ==========================================================================

// --------------------------- Firmware meta ---------------------------------
#define FW_VERSION "0.2.0-touch"
#define SERIAL_BAUD 115200

// --------------------------- WiFi ------------------------------------------
#define WIFI_SSID "Lab-Modul"
#define WIFI_PASSWORD "GVe836Nf"
#define WIFI_RECONNECT_MS 10000
#define WIFI_CONNECT_TIMEOUT_MS 15000

// --------------------------- Supabase (REST) -------------------------------
#define SUPABASE_URL "https://jawqxuzlvvzsrobftupx.supabase.co"
#define SUPABASE_ANON_KEY                                                      \
  "eyJhbGciOiJIUzI1NiIsInR5cCI6IkpXVCJ9."                                      \
  "eyJpc3MiOiJzdXBhYmFzZSIsInJlZiI6Imphd3F4dXpsdnZ6c3JvYmZ0dXB4Iiwicm9sZSI6Im" \
  "Fub24iLCJpYXQiOjE3NzM4NjY2MjcsImV4cCI6MjA4OTQ0MjYyN30."                     \
  "FnvhOpqhZh9Z3j2XkIPla1wUbx3wAsaP4anr44Utrzs"
#define DEVICE_ID "44b0f051-549a-4b87-b67a-592254e5c84f"

// --------------------------- Display (ILI9341 320x240, touch XPT2046) ------
// Concrete pins live in User_Setup.h (TFT_eSPI). Touch shares the SPI bus.
//   MOSI = 23  MISO = 19  SCLK = 18  TFT_CS = 5  DC = 22  RST = 4
//   TOUCH_CS = 21        (no backlight pin — BL wired to VCC)
// Rotation 1 = landscape 320x240.
#define DISPLAY_ROTATION 1
#define TOUCH_CS 21

// --------------------------- I2C (shared bus for future peripherals) -------
// DS3231 RTC removed. I2C pins kept in case other I2C devices are added.
#define I2C_SDA 32
#define I2C_SCL 33
#define I2C_CLOCK_HZ 400000

// --------------------------- HX711 + Load Cell -----------------------------
#define HX711_DT 16
#define HX711_SCK 17
#define HX711_GAIN 128
#define HX711_SAMPLES 5
// Obtained via calibration routine (see Scale.ino -> scaleCalibrate()).
#define HX711_CALIBRATION_FACTOR -2027.0f
#define SCALE_STABLE_THRESHOLD_G 0.3f

// --------------------------- DHT22 -----------------------------------------
#define DHT_PIN 14
#define DHT_READ_INTERVAL_MS 2500 // DHT22 minimum sampling is ~2s

// --------------------------- Stepper NEMA 17 + DRV8825 ---------------------
#define STEPPER_STEP 26
#define STEPPER_DIR 27
#define STEPPER_EN 25                  // Active-LOW enable
#define STEPPER_STEPS_PER_REV 200      // 1.8°/step motor
#define STEPPER_MICROSTEPS 16          // Wire MS1/MS2/MS3 accordingly
#define STEPPER_MAX_SPEED 2000.0f      // steps/s (after microstepping)
#define STEPPER_ACCEL 1500.0f          // steps/s^2
#define STEPPER_DISPENSE_SPEED 1200.0f // nominal feed speed
#define STEPPER_MAX_RUN_MS 30000       // hard safety timeout per cycle

// Nominal grams per second at STEPPER_DISPENSE_SPEED. The control loop is
// gravimetric (reads the scale), so this is only used to predict timing.
#define STEPPER_FEED_RATE_GPS 8.0f

// --------------------------- Feeder defaults -------------------------------
#define DEFAULT_PORTION_G 25.0f
#define MIN_PORTION_G 5.0f
#define MAX_PORTION_G 500.0f
#define FEED_TOLERANCE_G 1.5f

// Gravimetric stop: the auger stops when the scale reads this fraction of the
// target. The food still in flight in the channel completes the 100%, which
// avoids over-dispensing.
#define FEED_STOP_THRESHOLD 0.90f
// Non-blocking settling time after the auger stops, to let in-flight food land
// before reading the final dispensed weight.
#define FEED_SETTLE_MS 500

// --------------------------- Timings ---------------------------------------
#define TELEMETRY_INTERVAL_MS 2000
#define HEARTBEAT_INTERVAL_MS 30000
#define COMMAND_POLL_INTERVAL_MS 5000
#define CONFIG_POLL_INTERVAL_MS 60000
#define REALTIME_WEIGHT_INTERVAL_MS 500
#define DISPLAY_REFRESH_MS 250

// --------------------------- Device state & structures ---------------------
enum DeviceState {
  STATE_BOOT,
  STATE_IDLE,
  STATE_DISPENSING,
  STATE_ERROR,
  STATE_OFFLINE_DEGRADED
};
extern DeviceState currentState;
extern const char *lastErrorMessage;

struct Telemetry {
  float weightG; // current net weight on the tray
  float temperatureC;
  float humidity;
  bool wifiUp;
};
extern Telemetry telemetry;
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

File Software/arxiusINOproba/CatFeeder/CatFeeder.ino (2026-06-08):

// CatFeeder.ino — Main orchestrator
// Integrated Project II — GR15 [GEMEC-09UV]  Universitat de Vic — UCC
// ==========================================================================
// This sketch coordinates every physical subsystem of the automatic cat
// feeder: stepper dispenser, load cell (HX711), DHT22, ILI9341
// touch display (touch-only UI) and the Supabase cloud link.
// NOTE: DS3231 RTC removed to avoid I2C conflicts; time is managed via
// millis() and NTP-sourced timestamps from Supabase are used instead.
//
// The main loop is strictly non-blocking: all periodic tasks are driven by
// millis() timers and the stepper is stepped via AccelStepper::run().
// ==========================================================================

#include "config.h"

#include <Arduino.h>
#include <SPI.h>
#include <WiFi.h>
#include <Wire.h>

#include <AccelStepper.h>
#include <ArduinoJson.h>
#include <DHT.h>
#include <HX711.h>
#include <TFT_eSPI.h>

// Shared types referenced by auto-generated prototypes that the IDE hoists to
// the top of this (first) tab — must be visible here.
#include "schedules.h"

// ---------- Global peripheral objects (used from every *.ino tab) ----------
TFT_eSPI tft = TFT_eSPI();
HX711 scale;
DHT dht(DHT_PIN, DHT22);
AccelStepper stepper(AccelStepper::DRIVER, STEPPER_STEP, STEPPER_DIR);

// ---------- System-wide state --------------------------------------------
DeviceState currentState = STATE_BOOT;
const char *lastErrorMessage = "";

// Live sensor snapshot (updated by updateSensors()).
Telemetry telemetry = {0.0f, NAN, NAN, false};

// Active dispensing cycle descriptor.
FeedingCycle cycle = {false, 0.0f, 0.0f, 0.0f, 0, 0, "manual", "", "", "", ""};

// ---- Cross-tab schedule state (defined in ScheduleManager.ino) -----------
extern uint8_t  scheduleCount;

// Periodic-task timers.
static uint32_t tLastSensors      = 0;
static uint32_t tLastDisplay      = 0;
static uint32_t tLastHeartbeat    = 0;
static uint32_t tLastCmdPoll      = 0;
static uint32_t tLastCfgPoll      = 0;
static uint32_t tLastWifiTry      = 0;
static uint32_t tLastWeightPublish = 0;   // publish weight even when idle
#define IDLE_WEIGHT_PUBLISH_MS 10000      // every 10 s in idle state

// ==========================================================================
//                                   SETUP
// ==========================================================================
void setup() {
  Serial.begin(SERIAL_BAUD);
  delay(150);
  Serial.println();
  Serial.println(F("========================================"));
  Serial.println(F("  CatFeeder — firmware " FW_VERSION));
  Serial.println(F("========================================"));

  // No physical buttons on this hardware — the UI is touch-only.

  // --- Stepper driver off until we really need it ---------------------------
  pinMode(STEPPER_EN, OUTPUT);
  digitalWrite(STEPPER_EN, HIGH); // disabled (active-low)

  touchInputInit();

  displayInit();
  displaySplash("Booting...");

  i2cInit();
  scaleInit();
  sensorsInit();
  motorInit();
  networkInit();

  touchUIInit();

  currentState = STATE_IDLE;
  displaySplash("Ready");
  delay(400);

  Serial.println(F("[boot] complete"));
}

// ==========================================================================
//                                   LOOP
// ==========================================================================
void loop() {
  const uint32_t now = millis();

  // Motor stepping is now handled inside runDispensingCycle() via direct GPIO.
  // (AccelStepper kept in headers for motorInit compatibility but not used
  //  for dispensing — direct micros()-based pulses match Test_Motor.ino.)

  // 2) Touch input (reads touchscreen and drives UI screen state).
  static uint32_t tLastTouchUpdate = 0;
  if (now - tLastTouchUpdate >= 60) {
    tLastTouchUpdate = now;
    touchInputUpdate();
  }

  // 3) State machine.
  switch (currentState) {
  case STATE_IDLE:
    if (uiRequestedMode == UI_MODE_AUTO) {
      checkScheduledFeeds();
    }
    break;
  case STATE_DISPENSING:
    runDispensingCycle();
    if (now - cycle.lastPublishMs >= REALTIME_WEIGHT_INTERVAL_MS) {
      cycle.lastPublishMs = now;
      if (telemetry.wifiUp) {
        publishRealtimeWeight(telemetry.weightG, cycle.dispensedG, cycle.targetG);
      }
    }
    break;
  case STATE_ERROR:
    // Handled in touchInputUpdate(): clicking anywhere clears the error state.
    break;
  default:
    break;
  }

  // 5) Periodic sensor sampling.
  if (now - tLastSensors >= TELEMETRY_INTERVAL_MS) {
    tLastSensors = now;
    updateSensors();
  }

  // 6) Display refresh (no-op until the display phase).
  if (now - tLastDisplay >= DISPLAY_REFRESH_MS) {
    tLastDisplay = now;
    displayUpdate();
  }

  // 7) Network-bound tasks (skip cleanly when offline).
  if (WiFi.status() == WL_CONNECTED) {
    if (!telemetry.wifiUp) {
      telemetry.wifiUp = true;
      // WiFi just connected: sync heartbeat (gets time) and configs immediately
      tLastHeartbeat = now;
      sendHeartbeat();
      tLastCfgPoll = now;
      pollDeviceConfig();
      tLastCmdPoll = now;
      pollPendingCommands();
    }
    if (now - tLastCmdPoll >= COMMAND_POLL_INTERVAL_MS) {
      tLastCmdPoll = now;
      pollPendingCommands();
    }
    if (now - tLastCfgPoll >= CONFIG_POLL_INTERVAL_MS) {
      tLastCfgPoll = now;
      pollDeviceConfig();
    }
    if (now - tLastHeartbeat >= HEARTBEAT_INTERVAL_MS) {
      tLastHeartbeat = now;
      sendHeartbeat();
    }
    // Publish current weight every 10 s even when idle so the webapp
    // "Live Sensor Readings" always shows an up-to-date value.
    if (!cycle.active && now - tLastWeightPublish >= IDLE_WEIGHT_PUBLISH_MS) {
      tLastWeightPublish = now;
      publishRealtimeWeight(telemetry.weightG, 0, 0);
    }
  } else {
    telemetry.wifiUp = false;
    if (now - tLastWifiTry >= WIFI_RECONNECT_MS) {
      tLastWifiTry = now;
      networkReconnect();
    }
  }
}

// ==========================================================================
//                    Helpers exposed to every subsystem
// ==========================================================================
void i2cInit() {
  Wire.begin(I2C_SDA, I2C_SCL);
  Wire.setClock(I2C_CLOCK_HZ);
  Serial.println(F("[i2c] started"));
}

void goToError(const char *message) {
  lastErrorMessage = message;
  currentState = STATE_ERROR;
  motorEmergencyStop();
  Serial.print(F("[ERROR] "));
  Serial.println(message);
}

void clearError() {
  lastErrorMessage = "";
  currentState = STATE_IDLE;
  Serial.println(F("[ERROR] cleared"));
}
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

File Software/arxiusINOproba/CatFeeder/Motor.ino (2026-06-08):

// ==========================================================================
// Motor.ino — NEMA 17 via DRV8825 (STEP / DIR / ENABLE, EN active-LOW)
// ==========================================================================
// Step generation uses ESP32 hardware LEDC (PWM) so the pulse train is
// completely independent of the main-loop timing. This is equivalent to
// Test_Motor.ino's blocking delayMicroseconds() approach but non-blocking.
//
// LEDC channel 0 → STEPPER_STEP pin (GPIO 26)
// Frequency: MOTOR_STEP_HZ (625 Hz = 625 microsteps/s)
// With 16× microstepping: 625/16 = 39 full steps/s ≈ 11.7 RPM
// (Test_Motor used 500 steps/s = 9.4 RPM — same order, proven working)
//
// Gravimetric stop at 90% + 500 ms non-blocking settle.
// 2-second EMI dead zone at start of each cycle.
// 30-second hard safety timeout.
// ==========================================================================

// ESP32 core 3.x LEDC API doesn't require explicit channels
#define MOTOR_STEP_HZ       500    // microsteps per second (Matches Test_Motor: 1000us x2 = 500Hz)
#define MOTOR_LEDC_BITS     8      // 8-bit resolution (0-255)
#define MOTOR_DUTY_RUN      128    // 50% duty = square wave
#define MOTOR_DUTY_STOP     0      // 0% = no pulses

// Scale polling during dispensing
#define DISPENSE_SCALE_MS   300UL  // read scale at most once per 300 ms
static uint32_t lastScaleCheckMs = 0;

// Non-blocking settling sub-state
static bool     waitingFinalRead = false;
static uint32_t settleStartMs    = 0;

// --------------------------------------------------------------------------
void motorInit() {
  pinMode(STEPPER_EN,  OUTPUT);
  pinMode(STEPPER_DIR, OUTPUT);
  digitalWrite(STEPPER_EN,  HIGH);  // disabled (active-LOW)
  digitalWrite(STEPPER_DIR, LOW);   // DIRECCIO_NORMAL = LOW (same as Test_Motor)

  // Attach LEDC hardware PWM to the STEP pin (ESP32 Core 3.x API)
  ledcAttach(STEPPER_STEP, MOTOR_STEP_HZ, MOTOR_LEDC_BITS);
  ledcWrite(STEPPER_STEP, MOTOR_DUTY_STOP);  // not running yet

  Serial.println(F("[motor] stepper driver ready (LEDC hardware PWM)"));
}

// Direct EN control (active-LOW).
void motorEnable(bool on) {
  digitalWrite(STEPPER_EN, on ? LOW : HIGH);
}

// Immediately stop pulses and cut driver power.
void motorEmergencyStop() {
  ledcWrite(STEPPER_STEP, MOTOR_DUTY_STOP);
  motorEnable(false);
  cycle.active     = false;
  waitingFinalRead = false;
  Serial.println(F("[motor] emergency stop"));
}

// Orderly stop of manual dispensing (starts settling phase).
void stopDispense() {
  if (currentState == STATE_DISPENSING && cycle.active && !waitingFinalRead) {
    ledcWrite(STEPPER_STEP, MOTOR_DUTY_STOP);  // stop PWM
    motorEnable(false);
    waitingFinalRead = true;
    settleStartMs    = millis();
    Serial.printf("[motor] manual dispense stopped — settling %ums\n", (unsigned)FEED_SETTLE_MS);
  }
}
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

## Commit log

2026-02-26 Create Tutorials.md
    Add HX711 and Stepper motor tutorials
2026-03-17 He afegit tot lo relacionat amb la web app i software, icnlos un programa que simula dades.
2026-03-19 He borrat el testing de la webapp i el mock per començar amb el final.
2026-03-19 Add files via upload
    Add ESP32-WROOM 32 PIN OUT
2026-03-19 Fix firmwares: resolve C++ type error in ternary operators & add 10s idle weight pushing
    [CatFeeder_Mock.ino]
2026-04-16 feat: initialize CatFeeder firmware project with modular hardware drivers and configuration settings
2026-04-16 refactor: reassign hardware pins to resolve conflicts and add documentation for integration steps
    [CatFeeder.ino, config.h]
2026-04-16 config.h moved into the correct folder
    [config.h]
2026-04-21 feat: add touch UI implementation including hardware pin configuration and new TouchUI module
2026-04-28 feat: add touchscreen UI prototype with unlock pattern and screensaver states
2026-05-05 Rename image.jpg to .esp32_pinout.jpg
    rename pin out esp32 image
2026-05-05 Add files via upload
    Datasheet of NEMA 17 motor
2026-05-05 Create README.md
    creation of readme for schematics folder
2026-05-05 Rename Electronics/pins.md to Electronics/Schematics/pins.md
    move pins to schematics
2026-05-21 refactor: update hardware pin mapping for touch and weight sensor calibration logic
2026-05-28 feat: implement motor jamming protection and update touchscreen unlock sequence in test sketches
    [Test_Motor.ino, probaMenuTouch.ino]
2026-06-01 refactor: update hardware driver to ILI9341 and adjust UI layout and scaling for smaller screen dimensions
2026-06-01 feat: implement manual touch calibration tool and update hardware pin definitions and calibration values in User_Setup
2026-06-02 feat(firmware): complete ESP32 Supabase integration with gravimetric motor control
    Implement full firmware integration connecting ESP32 hardware peripherals
    to the Supabase backend, replacing physical buttons with touch-only input
    and completing all cloud communication functions.
    Key changes:
    - config.h: fix DHT_PIN 33→14 (was colliding with I2C_SCL), add TOUCH_CS=21,
    FEED_STOP_THRESHOLD=0.90, remove all physical button pin definitions
    - User_Setup.h: new TFT_eSPI config for ILI9341 320×240 with XPT2046 touch
    - schedules.h: new shared Schedule struct (MAX_SCHEDULES=20)
    - TouchInput.ino: replaces Inputs.ino — XPT2046 touch-only input (no render),
    exposes uiRequestedMode and uiManual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
    [CatFeeder.ino, Display.ino, Motor.ino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]
2026-06-05 feat: add comprehensive touch interface prototype, improve sensor initialization robustness, and optimize telemetry sampling.
2026-06-07 3D parts
    [Base.3mf, Bowl Plate.3mf, Bowl.3mf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]
2026-06-08 refactor: modularize touch UI, motor control, and device state management into config-driven architecture
